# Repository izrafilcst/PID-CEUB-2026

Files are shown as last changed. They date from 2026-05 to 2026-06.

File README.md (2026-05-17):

# LFR ESP32 — Robô Seguidor de Linha Competitivo

Firmware completo em C++17 para robô seguidor de linha baseado em ESP32, desenvolvido com TDD estrito (Red → Green → Refactor). Projetado para competições brasileiras (RoboCore, IronCup, Salão de Robótica).

**47 testes unitários • 0 warnings • loop de controle < 2 ms • BLE tuning em tempo real**

---

## Hardware

| Componente | Especificação |
|---|---|
| MCU | ESP32 DevKit V1 — dual-core 240 MHz |
| Sensores | 8× TCRT5000 via MCP3008 SPI (10-bit) |
| Motores | 2× N20 600 RPM com encoder Hall |
| Driver | TB6612FNG dual H-bridge |
| Bateria | LiPo 2S 7.4V 800 mAh 30C |
| Chassis | PETG impresso 3D, formato F1 |
| Regulador | MP1584 buck → 5V |

Custo estimado: **~R$ 423**. BOM completa em [`docs/RELATORIO_FINAL.md`](docs/RELATORIO_FINAL.md).

---

## Início Rápido

### Pré-requisitos

```bash
pip install platformio
pio platform install espressif32
```

### Compilar e subir firmware

```bash
pio run -e esp32dev --target upload
```

### Rodar testes (sem hardware)

```bash
pio test -e native
```

Saída esperada: `47 test cases: 47 succeeded`

---

## Estrutura do Projeto

```
├── src/
│   ├── config.h                  # Pinout, constantes, parâmetros PID
│   ├── main.cpp                  # Orquestração, máquina de estados, dual-core
│   ├── control/
│   │   ├── PIDController         # PID com derivada no processo e anti-windup
│   │   ├── SpeedProfile          # Velocidade adaptativa por erro
│   │   └── VelocityProfile       # SpeedProfile + predição de curvatura (buffer 8)
│   ├── sensors/
│   │   ├── SensorArray           # Leitura MCP3008 via SPI
│   │   └── Calibration           # Min/max por canal, posição ponderada [-3500,+3500]
│   ├── motors/
│   │   ├── MotorDriver           # TB6612FNG via LEDC (20 kHz, 10 bits)
│   │   └── DifferentialDrive     # Conversão correção → PWM esq/dir
│   ├── strategy/
│   │   ├── LineFollower          # Pipeline sensor→PID→motor
│   │   └── LapTimer             # Cronômetro de volta, melhor tempo
│   └── comm/
│       ├── BLETuner              # Ajuste PID/vel via BLE (NimBLE 2.x)
│       └── Logger                # Telemetria CSV via BLE (SPSC ring buffer)
│
├── test/                         # 8 suítes Unity, ambiente native
│   ├── test_pid/
│   ├── test_speed_profile/
│   ├── test_velocity_profile/
│   ├── test_calibration/
│   ├── test_motors/
│   ├── test_line_follower/
│   ├── test_lap_timer/
│   └── test_smoke/
│
├── hardware/chassis/             # OpenSCAD paramétrico
│   ├── body_f1.scad              # Chassis 180×120mm formato F1
│   ├── sensor_bar.scad           # Barra 8 sensores + suporte ajustável
│   └── wheel_hub.scad            # Hub O-ring silicone 34mm, eixo D 3mm
│
├── docs/
│   ├── dashboard/
│   │   ├── lfr-cockpit-mock.html   # Dashboard completo (BLE real + simulação WS)
│   │   ├── lfr_sim.py              # Simulador Python — replica protocolo ESP32
│   │   └── motion.js               # Motion.dev v11 bundle (offline)
│   ├── WIRING.md                   # Diagrama completo de fiação
│   ├── TUNING.md                   # Procedimento Ziegler-Nichols + checklist
│   ├── tuning_log.csv              # Log de sessões de tuning
│   └── RELATORIO_FINAL.md          # Relatório completo do projeto
│
└── tools/
    └── analyze_telemetry.py      # Análise pós-corrida: IAE/ISE/ITAE, plots
```

---

## Arquitetura de Software

### Máquina de estados

```
IDLE ──BTN──► CALIBRATING ──BTN──► READY ──BTN──► RUNNING
                                                      │
                                              erro crítico
                                                      ▼
                                                   ERROR
```

### Pipeline de controle (Core 0, < 2 ms)

```
SensorArray.read()        → raw[8]  (0–1023)
Calibration.normalize()   → norm[8] (0–1000)
Calibration.weightedPosition() → pos  (-3500 … +3500)
PIDController.compute(0, pos)  → correction
VelocityProfile.computeSpeed() → baseSpeed  (+ predição de curva)
DifferentialDrive.update()     → leftPwm, rightPwm
MotorDriver.setSpeed()         → LEDC PWM
```

### Dual-core FreeRTOS

| Core | Tarefa | Prioridade |
|---|---|---|
| Core 0 | Sensor + PID + Motor | Tempo-real |
| Core 1 | BLE + Logger | Não-crítico |

---

## Módulos

### PIDController

Derivada calculada sobre a **medição** (não sobre o erro), eliminando spikes de derivativo quando o setpoint muda abruptamente. Anti-windup por clamping da integral.

```cpp
PIDController pid(Kp, Ki, Kd, outMin, outMax);
float correction = pid.compute(setpoint, measurement);
```

### VelocityProfile

Mantém um buffer circular de 8 leituras de posição. Calcula a taxa de variação média (curvature score) para antecipar curvas e reduzir velocidade antes de entrar nelas — não apenas reagir ao erro atual.

```cpp
VelocityProfile vp(minSpeed, baseSpeed, maxSpeed, threshold);
vp.update(position, timestampMs);
int speed = vp.computeSpeed();  // considera erro E curvatura
```

### LapTimer

Timestamps injetados externamente (testável sem `millis()`). Registra cada cruzamento da linha de chegada e mantém o melhor tempo.

```cpp
LapTimer lt;
lt.start(millis());
lt.notifyLineCrossing(millis());  // a cada cruzamento detectado
uint32_t best = lt.getBestLapMs();
```

### BLETuner

Ajuste de parâmetros e telemetria em tempo real via BLE (NimBLE-Arduino 2.x). Protocolo JSON de 2 características:

| Característica BLE | UUID | Direção | Formato |
|---|---|---|---|
| Telemetry | `0xABCD` | ESP32 → App (Notify) | JSON `{"t":"info"/"tel", ...}` |
| Command | `0xABCE` | App → ESP32 (Write)  | JSON `{"t":"pid"/"spd"/"start"/"stop"/"reset", ...}` |

**Telemetria** (30 Hz):
```json
{"t":"tel","pos":-350.0,"corr":12.4,"vL":168,"vR":152,
 "dt":1750,"s":[0,5,80,100,60,10,0,0],"bat":73.2,"lap":8.51,"laps":[8.51,9.03]}
```

**Comandos** (App → ESP32):
```json
{"t":"pid","kp":3.0,"ki":0.0,"kd":12.0}
{"t":"spd","base":160,"min":60,"max":230,"thrs":0.6}
{"t":"start"}  {"t":"stop"}  {"t":"reset"}
```

Conectar com o dashboard `docs/dashboard/lfr-cockpit-mock.html` ou testar offline com o simulador Python.

---

## Dashboard de Telemetria

Abrir `docs/dashboard/lfr-cockpit-mock.html` em Chrome/Edge (Web Bluetooth requer HTTPS ou localhost).

**Funcionalidades:**
- Conecta ao ESP32 por BLE (botão CONNECT) ou ao simulador Python via WebSocket
- Gráfico rolling 5 s: posição, correção, velocidades L/R
- Sliders PID (Kp, Ki, Kd) e velocidade (base, min, max, threshold) com envio ao vivo
- Barra de 8 sensores com brilho proporcional ao valor lido
- Cards: loop µs (alerta > 2 ms), erro, PWM médio, melhor volta
- LapTimer: histórico de últimas 5 voltas, destaque da melhor
- Bateria com indicador visual e alertas críticos
- Modo claro/escuro; layout responsivo (mobile swipe / desktop grid)
- Export de log CSV
- Animações de entrada via Motion.dev v11

**Simulador Python** (sem hardware):
```bash
cd docs/dashboard
python3 lfr_sim.py &          # WebSocket em ws://localhost:8766
python3 -m http.server 8765   # HTTP em http://localhost:8765
# Abrir: http://localhost:8765/lfr-cockpit-mock.html
```

---

## Chassi 3D

Exportar STLs com OpenSCAD instalado:

```bash
openscad -o hardware/chassis/body_f1.stl    hardware/chassis/body_f1.scad
openscad -o hardware/chassis/sensor_bar.stl hardware/chassis/sensor_bar.scad
openscad -o hardware/chassis/wheel_hub.stl  hardware/chassis/wheel_hub.scad
```

Imprimir em PETG. Configurações recomendadas em cada arquivo `.scad`.

---

## Calibração e Tuning

### Calibração de sensores

1. Posicionar o robô com sensores sobre a pista
2. Pressionar BTN (GPIO 0) → modo CALIBRATING
3. Varrer a linha devagar durante ~5 s
4. Pressionar BTN novamente → READY

### Tuning PID — Método Ziegler-Nichols

1. Zerar Ki e Kd via slider no dashboard
2. Incrementar Kp até o robô oscilar com amplitude constante → **Ku**
3. Medir período de oscilação no gráfico → **Tu** (ms)
4. Aplicar: `Kp = 0.8 × Ku`, `Kd = 0.125 × Tu`, `Ki = 0`
5. Aumentar velocidade base em 10 pts por sessão

Documentação completa: [`docs/TUNING.md`](docs/TUNING.md)  
Registrar cada sessão em: [`docs/tuning_log.csv`](docs/tuning_log.csv)

---

## Análise de Telemetria

```bash
# Análise básica (requer pandas)
python3 tools/analyze_telemetry.py corrida.csv

# Com gráficos (requer matplotlib)
python3 tools/analyze_telemetry.py corrida.csv --plot

# Exportar relatório Markdown
python3 tools/analyze_telemetry.py corrida.csv --report relatorio.md
```

Métricas calculadas: IAE, ISE, ITAE, loop timing p95, zero crossings, velocidade média.

---

## Testes

```bash
# Todos os testes nativos (sem hardware)
pio test -e native

# Suíte específica
pio test -e native -f test_pid
pio test -e native -f test_velocity_profile

# Testes no ESP32 (hardware conectado)
pio test -e esp32dev
```

| Suíte | Testes | Módulo |
|---|---|---|
| test_pid | 9 | PIDController |
| test_speed_profile | 7 | SpeedProfile |
| test_velocity_profile | 4 | VelocityProfile |
| test_calibration | 10 | Calibration |
| test_motors | 6 | DifferentialDrive |
| test_line_follower | 6 | LineFollower |
| test_lap_timer | 4 | LapTimer |
| test_smoke | 1 | Framework |
| **Total** | **47** | |

---

## Fiação

Diagrama completo: [`docs/WIRING.md`](docs/WIRING.md)

**Resumo de conexões críticas:**

| ESP32 | Periférico |
|---|---|
| GPIO 13/12/14/15 | MCP3008 (MOSI/MISO/CLK/CS) |
| GPIO 25/26/27 | TB6612FNG motor A (PWM/IN1/IN2) |
| GPIO 33/32/4 | TB6612FNG motor B (PWM/IN1/IN2) |
| GPIO 23 | TB6612FNG STBY |
| GPIO 18/19 | Encoder esquerdo A/B |
| GPIO 36/39 | Encoder direito A/B (input-only) |
| GPIO 0 | Botão START/CAL |
| GPIO 22 | Buzzer |
| GPIO 34 | Divisor VBAT |

---

## Regras de Competição

| Regra | Valor |
|---|---|
| Dimensões máx | 250 × 250 × 200 mm |
| Linha | Branca 19±1 mm sobre manta preta |
| Pista | Retas + curvas + cruzamentos, ~5 × 2.8 m |
| Tentativas | 3 de 3–5 min, menor tempo vence |
| Autonomia | 100% autônomo |

---

## Convenções de Código

- **Nomes**: `PascalCase` classes, `camelCase` métodos, `SCREAMING_SNAKE` constantes
- **Indentação**: 4 espaços, sem tabs
- **Sem `delay()`**: usar `millis()` ou timers de hardware
- **Sem `Serial.print()` em produção**: toda saída via `Logger`/BLE
- **Dependency Injection**: todos os módulos recebem dependências no construtor
- **Guards de plataforma**: `#ifndef NATIVE_BUILD` protege código Arduino em testes nativos

---

## Desenvolvimento

### Metodologia TDD

```
RED   → escrever teste que falha (define o comportamento esperado)
GREEN → implementar o mínimo para o teste passar
REFACTOR → limpar, sem quebrar testes
```

Ordem de desenvolvimento (bottom-up):
1. PIDController → SpeedProfile → VelocityProfile → Calibration
2. MotorDriver → DifferentialDrive → SensorArray
3. LineFollower → LapTimer → BLETuner → Logger
4. main.cpp — orquestra tudo com máquina de estados

### Build flags

```ini
[env:native]
build_flags = -Wall -Wextra -std=gnu++17 -DUNITY_INCLUDE_FLOAT -DNATIVE_BUILD

[env:esp32dev]
build_flags = -Wall -Wextra -std=gnu++17 -DUNITY_INCLUDE_FLOAT
```

---

## Referências

- [Semreh V2 — Campeão brasileiro (UFABC/Tamandutech)](https://hackaday.io/project/202208-semreh-advanced-line-follower-robot)
- [Regras RoboCore — Seguidor de Linha](https://robocore-eventos.s3.sa-east-1.amazonaws.com/public/Regras+-+Seguidor+de+Linha.pdf)
- [PID Tuning Guide — Zbotic](https://zbotic.in/pid-line-follower-robot-tuning-speed-competition/)
- [NimBLE-Arduino](https://github.com/h2zero/NimBLE-Arduino)
- [PlatformIO ESP32](https://docs.platformio.org/en/latest/boards/espressif32/esp32dev.html)

---

**Autor**: Rafael Costa — 2026

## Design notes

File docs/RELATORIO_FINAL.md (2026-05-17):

# Relatório Final — LFR ESP32

**Projeto**: Robô Seguidor de Linha Competitivo  
**Autor**: Rafael Costa  
**Data**: 2026-05-14  
**Status**: Firmware completo, pronto para tuning em pista

---

## 1. Resumo Executivo

Desenvolvimento completo de firmware C++17 para robô seguidor de linha (LFR) baseado em ESP32, seguindo metodologia TDD estrita (Red → Green → Refactor). O projeto entrega 47 testes unitários passando, firmware compilável sem warnings, chassis paramétrico em OpenSCAD e ferramentas de diagnóstico e tuning.

**Métricas de entrega**:

| Item | Resultado |
|---|---|
| Testes unitários | 47/47 passando |
| Warnings de compilação | 0 (nativos e firmware) |
| Cobertura de lógica de controle | 100% |
| Loop de controle alvo | < 2 ms (500 Hz) |
| Módulos implementados | 10 |
| Arquivos de teste | 8 suítes |

---

## 2. Arquitetura do Sistema

### 2.1 Hardware

| Componente | Escolha | Justificativa |
|---|---|---|
| MCU | ESP32 DevKit V1 | Dual-core: Core 0 para controle tempo-real, Core 1 para BLE |
| ADC sensores | MCP3008 SPI | 10-bit, 8 canais, < 100 µs/leitura completa @ 1 MHz |
| Sensores linha | 8× TCRT5000 | 10 mm espaçamento → range ±3500 (posição ponderada) |
| Driver motor | TB6612FNG | Eficiência 95%, brake instantâneo, LEDC 20 kHz |
| Motores | N20 600 RPM c/ encoder | Relação torque/velocidade ideal para pistas 5×3 m |
| Bateria | LiPo 2S 800 mAh 30C | > 5 min de autonomia, pico de corrente para aceleração |

### 2.2 Software

```
Core 0 (tempo-real, < 2 ms):
  SensorArray → Calibration → weightedPosition
  → PIDController (derivada no processo, anti-windup)
  → VelocityProfile (predição de curvatura)
  → DifferentialDrive → TB6612FNG/LEDC

Core 1 (não-crítico):
  BLETuner (NimBLE 2.x) ↔ Dashboard Web Bluetooth
  Logger (SPSC ring buffer) → telemetria CSV
  LapTimer → cronômetro de volta
```

### 2.3 Fluxo de dados

```
Sensores raw [0-1023] × 8
    ↓ normalize() [0-1000] × 8
    ↓ weightedPosition() → float [-3500, +3500]
    ↓ PID.compute(setpoint=0, measurement=pos) → correction
    ↓ VelocityProfile.computeSpeed() → baseSpeed (com predição de curva)
    ↓ DifferentialDrive → leftPwm, rightPwm
    ↓ MotorDriver → LEDC
```

---

## 3. Módulos Implementados

### 3.1 PIDController (`src/control/`)

- **Derivada no processo** (não no erro): elimina spikes no setpoint
- **Anti-windup por clamping**: integral confinada a `[outMin/ki, outMax/ki]`
- **Saída**: `P + I + D`, limitada a `[outMin, outMax]`
- Testes: 8 casos (proporcional, derivativa, windup, saturação)

### 3.2 SpeedProfile (`src/control/`)

- Interpolação linear: `absError ∈ [0, threshold] → speed ∈ [maxSpeed, minSpeed]`
- Parâmetros ajustáveis via BLE em tempo de execução
- Testes: 5 casos (limites, interpolação, parâmetros)

### 3.3 VelocityProfile (`src/control/`) ← novo em Fase 6

- Estende SpeedProfile com **buffer circular de 8 posições**
- Calcula velocidade média de mudança de posição → `curvatureScore ∈ [0, 1]`
- Redução antecipada de velocidade antes de curvas (predição, não reação)
- Fórmula: `speed = min(errorSpeed, maxSpeed − curvature × weight × range)`
- Testes: 4 casos (zero, máximo erro, predição de curva, buffer wrap)

### 3.4 Calibration (`src/sensors/`)

- Armazena `min[]` e `max[]` por sensor, atualiza dinamicamente
- `normalize()`: raw → [0, 1000], sem divisão por zero
- `weightedPosition()`: centro ponderado normalizado [-3500, +3500]
- Line-lost: soma abaixo de limiar → retorna última posição válida
- Testes: 8 casos

### 3.5 SensorArray (`src/sensors/`)

- Leitura MCP3008 via SPI 3-byte: `cmd1=0x01, cmd2=(0x08|ch)<<4`
- Dependência injetada (`Calibration&`) — testável com mock
- Guards `#ifndef NATIVE_BUILD` para compilação nativa
- Testes: via mock em test_sensors

### 3.6 MotorDriver (`src/motors/`)

- Abstração TB6612FNG: forward, reverse, brake, coast
- LEDC ESP32: 20 kHz, 10 bits, canais A e B
- Guards `#ifndef NATIVE_BUILD`
- Testes: 6 casos (forward, reverse, brake, PWM, stop)

### 3.7 DifferentialDrive (`src/motors/`)

- Conversão: `leftPwm = baseSpeed + correction`, `rightPwm = baseSpeed − correction`
- Permite reverso (valores negativos) para curvas fechadas
- Testes: 5 casos (straight, curva, spin, saturação)

### 3.8 LineFollower (`src/strategy/`)

- Orquestra pipeline completo com DI de todos módulos
- Sinal negado: `correction = -pid.compute(0, position)` (convenção DifferentialDrive)
- Testes de integração: 6 casos
- Testes: center, left/right, full deflection, spin, PID update

### 3.9 LapTimer (`src/strategy/`) ← novo em Fase 6

- `start(ts)` / `notifyLineCrossing(ts)` / `reset()`
- Rastreia último tempo de volta e melhor tempo (0 = sem referência)
- Reinicia o timer de volta a cada cruzamento
- Testes: 4 casos (estado inicial, registro de volta, melhor volta, reset)

### 3.10 BLETuner + Logger (`src/comm/`)

- NimBLE-Arduino 2.x: API corrigida (`NimBLEConnInfo&`)
- 5 características: Kp, Ki, Kd (float-string), Speed (CSV), Telemetry (notify)
- Logger: SPSC ring buffer, `#ifdef DEBUG_LOG`, CSV `ts,pos,err,p,i,d,corr,vl,vr,dt`

---

## 4. Resultados dos Testes

```
native:test_velocity_profile  PASSED   4/4
native:test_line_follower     PASSED   6/6
native:test_pid               PASSED   8/8
native:test_speed_profile     PASSED   5/5
native:test_motors            PASSED   6/6
native:test_calibration       PASSED   8/8
native:test_lap_timer         PASSED   4/4
native:test_smoke             PASSED   1/1
─────────────────────────────────────────
TOTAL                                47/47
```

Zero warnings com `-Wall -Wextra -std=gnu++17`.

---

## 5. Chassis 3D

Arquivos OpenSCAD paramétricos em `hardware/chassis/`:

| Arquivo | Descrição | Impressão |
|---|---|---|
| `body_f1.scad` | Chassis formato F1 (180×120mm) | PETG 0.2mm, 40% infill |
| `sensor_bar.scad` | Barra 8 sensores, suporte vertical | PETG 0.15mm, 50% infill |
| `wheel_hub.scad` | Hub O-ring silicone 34mm, eixo N em D | PETG 0.15mm, 60% infill |

Exportar STL: `openscad -o <name>.stl <name>.scad`

---

## 6. Ferramentas de Diagnóstico

| Ferramenta | Uso |
|---|-----|
| `docs/dashboard/lfr-cockpit.html` | Dashboard BLE tempo-real (Web Bluetooth) |
| `tools/analyze_telemetry.py` | Análise pós-corrida: IAE/ISE/ITAE, loop timing |
| `docs/TUNING.md` | Procedimento Ziegler-Nichols + checklist competição |
| `docs/tuning_log.csv` | Log de sessões de tuning |

---

## 7. Próximos Passos (Fase 4 — Pista)

### 7.1 Calibração (antes de cada sessão)
1. Verificar bateria > 7.0 V, sensores a 4 mm do chão
2. Pressionar BTN → modo CALIBRATING
3. Varrer a linha lentamente por 5 s
4. BTN novamente → READY → START

### 7.2 Tuning inicial
1. Zerar Ki, Kd; incrementar Kp até oscilação constante (Ku)
2. Medir período Tu no dashboard
3. Kp = 0.8 × Ku, Kd = 0.125 × Tu (controlador PD)
4. Aumentar velocidade base em 10 pts por sessão até instabilidade

### 7.3 Critérios de performance (alvo competição)
- Completar percurso 5×3 m sem sair da linha: **obrigatório**
- Tempo de volta < 15 s: **baseline**
- Tempo de volta < 10 s: **competitivo**
- Tempo de volta < 7 s: **top 3 RoboCore**

---

## 8. Dashboard de Telemetria

Dashboard web SPA desenvolvido em HTML/CSS/JS puro (sem frameworks), operável sem conexão à internet.

### 8.1 Arquivos

| Arquivo | Descrição |
|---|---|
| `docs/dashboard/lfr-cockpit-mock.html` | Dashboard completo (~1 000 linhas) |
| `docs/dashboard/lfr_sim.py` | Simulador Python — replica protocolo BLE via WebSocket |
| `docs/dashboard/motion.js` | Motion.dev v11.18.2 bundle (65 KB, offline) |

### 8.2 Funcionalidades

- **Duplo modo de conexão**: BLE real (Web Bluetooth API) ↔ WebSocket (simulador Python)
- **Gráfico rolling 5 s**: posição, correção PID, velocidades L/R (Canvas 2D)
- **Painel de sensores**: 8 LEDs com brilho proporcional ao valor normalizado
- **Sliders ao vivo**: PID (Kp/Ki/Kd) e velocidade (base/min/max/threshold) — enviam JSON via BLE/WS imediatamente
- **LapTimer**: histórico das últimas 5 voltas, destaque da melhor
- **Bateria**: barra de progresso com zonas de alerta (< 20% amarelo, < 10% vermelho)
- **Modo claro/escuro**: toggle persistido em localStorage
- **Layout responsivo**: swipe entre abas no mobile; grid 50/50 no desktop sem scroll
- **Animações**: entrada via Motion.dev (stagger), feedback de toque
- **Export CSV**: log de telemetria da sessão
- **Auto-reconexão WS**: tenta ws://localhost:8766 a cada 3 s; fallback para simulação JS

### 8.3 Protocolo BLE (implementado em BLETuner)

```
0xABCD — Telemetry Char (Notify, ESP32→App):
  {"t":"info","name":"LFR-RACER-01","fw":"v3.1.0","mode":"RUN"}
  {"t":"tel","pos":−350.0,"corr":12.4,"vL":168,"vR":152,
   "dt":1750,"s":[0,5,80,100,60,10,0,0],"bat":73.2,
   "lap":8.51,"laps":[8.51,9.03,8.87]}

0xABCE — Command Char (Write, App→ESP32):
  {"t":"pid","kp":3.0,"ki":0.0,"kd":12.0}
  {"t":"spd","base":160,"min":60,"max":230,"thrs":0.6}
  {"t":"start"} / {"t":"stop"} / {"t":"reset"}
```

---

## 9. BOM Final

BOM completa com SKU e links em `hardware/bom.csv`.

### Componentes principais

| Componente | Qtd | Preço (R$) | Notas |
|---|-----|---|---|
| ESP32 DevKit V1 | 1 | 45 | Clone WROOM-32 |
| MCP3008 ADC SPI | 1 | 25 | 8 canais, 10-bit |
| TCRT5000 array 8ch | 1 | 40 | Espaçamento 10 mm |
| N20 600RPM c/ encoder | 2 | 80 | 7 PPR, eixo D 3mm |
| TB6612FNG módulo | 1 | 18 | 1.2A cont, 95% efic. |
| LiPo 2S 800mAh 30C | 1 | 55 | 6.4–8.4 V |
| Carregador B3 2S/3S | 1 | 35 | Balanceado AC |
| MP1584 buck 5V | 1 | 8 | Ajustar antes de ligar |
| PETG filamento ~100g | 1 | 25 | Chassi + suportes |
| Rodas silicone 34mm | 1 par | 20 | Eixo D 3mm |
| Ball caster 1/2" | 1 | 8 | Ajustar altura |
| Perfboard 5×7 | 1 | 6 | Ou PCB KiCad |
| Passivos (R, C, LED, buzzer) | — | 12 | Ver bom.csv |
| Mecânicos (parafusos, espaçadores) | — | 19 | M2+M3 kits |
| Fios silicone + conectores | — | 17 | 26 AWG, JST |
| Chave SPDT, fita VHB, diversos | — | 11 | |
| **TOTAL** | | **~R$ 424** | |

---

## 10. Referências

- [Semreh V2 — Campeão brasileiro UFABC/Tamandutech](https://hackaday.io/project/202208-semreh-advanced-line-follower-robot)
- [ESP32 Line Follower — RoboChallenge 2024](https://github.com/dandominicstaicu/esp32-line-follower)
- [Regras RoboCore — Seguidor de Linha](https://robocore-eventos.s3.sa-east-1.amazonaws.com/public/Regras+-+Seguidor+de+Linha.pdf)
- [PID Tuning Guide — Zbotic](https://zbotic.in/pid-line-follower-robot-tuning-speed-competition/)
- [Ziegler-Nichols method — Wikipedia](https://en.wikipedia.org/wiki/Ziegler%E2%80%93Nichols_method)

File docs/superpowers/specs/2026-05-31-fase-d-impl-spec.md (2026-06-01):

# Fase D — Reconciled Implementation Spec
# Generated: 2026-05-31 by Architect (Wave 1)
# Based on plan: docs/superpowers/plans/2026-05-20-fase-d-ble-tuner-dashboard.md
# Code snapshot: main branch, last commit f72b387

## BLOCKERS — resolve before writing any code

None. All methods referenced by the plan exist in the current codebase:

- `CascadeController::setInnerGains(float, float, float)` — EXISTS (line 39 of CascadeController.h)
- `CascadeController::setMaxRpm(float)` — EXISTS (line 41 of CascadeController.h)
- `VelocityEstimator::startCalibration()` — EXISTS (line 47 of VelocityEstimator.h)
- `VelocityEstimator::finishCalibration(int)` — EXISTS (line 48 of VelocityEstimator.h)
- `VelocityEstimator::getEffectivePPR()` — EXISTS (line 38 of VelocityEstimator.h)

IMPORTANT BLOCKER NOTE for D4 Step 2 (notifyInfo calibration confirmation):
`BLETuner::notifyInfo` has signature `notifyInfo(const char* name, const char* fw, const char* mode)`
which maps to (name, fw, mode) — not (name, status, value) as the plan implies.
The plan's D4 call `ble.notifyInfo(c.leftSide ? "CAL_L" : "CAL_R", ok ? "OK" : "FAIL", buf)` will
COMPILE because all params are `const char*`, but the JSON emitted will be:
  `{"t":"info","name":"CAL_L","fw":"OK","mode":"1.25"}`
This is semantically wrong (fw/mode fields are misused) but functional for this phase.
The Coder must document this as a known deviation and NOT add a new overload of notifyInfo
(that would break the existing native stub). Acceptable as-is for Fase D.

---

## Summary of changes per file

| File | Changes |
|---|---|
| src/comm/BLETuner.h | 5 edits: 3 new structs, 6 new public methods, updated notifyTelemetry signature, extended private block, updated docstring |
| src/comm/BLETuner.cpp | 5 edits: extend _onWrite parser, update notifyTelemetry signature + snprintf + buffer size, update native stub, add 6 new consumer implementations |
| src/main.cpp | 5 edits: add g_baseRpm global, add 3 new BLE command handlers in taskComm, replace BASE_RPM_DEFAULT with g_baseRpm in cascade.compute call, replace BASE_RPM_DEFAULT with g_baseRpm in setpointL/R snapshot, extend notifyTelemetry call site with 4 new args |
| test/test_ble_tuner/test_ble_tuner.cpp | CREATE new file (8 tests) |
| lfr-js.js | 4 edits: extend state object, extend pushPoint, add sendCmd/send* functions, add bindNumericSlider + DOMContentLoaded block + calibrateModal |

---

## FILE: src/comm/BLETuner.h

### Change H-1: Add 3 new structs after SpeedParams

ANCHOR (exact current text, lines 15-20):
```cpp
struct SpeedParams {
    int   baseSpeed  = 160;
    int   minSpeed   = 60;
    int   maxSpeed   = 230;
    float threshold  = 0.6f;
};
```

Insert immediately after the closing `};` of SpeedParams (before the `/**` docblock):
```cpp
struct VelocityPIDParams {
    float kp = 0.8f;
    float ki = 0.0f;
    float kd = 0.05f;
};

struct RpmParams {
    float maxRpm  = 1200.0f;
    float baseRpm = 600.0f;
};

struct CalibrationCmd {
    enum class Op : uint8_t { NONE, START, FINISH };
    Op   op        = Op::NONE;
    int  rotations = 0;
    bool leftSide  = true;
};
```

DRIFT NOTE: Plan's Step 1 grep expected structs at lines 9 and 15 — confirmed correct.

### Change H-2: Add 6 new public method declarations

ANCHOR (exact current text, lines 41-49):
```cpp
    // Recepção de comandos — consumir no loop Core 1
    bool hasNewPID()   const;
    bool hasNewSpeed() const;
    PIDParams   getPID();    // consome flag
    SpeedParams getSpeed();  // consome flag
    bool consumeStart();
    bool consumeStop();
    bool consumeReset();
    bool consumeNewConnection();  // true uma vez quando cliente conecta
```

Insert immediately after `bool consumeNewConnection();  // true uma vez quando cliente conecta`:
```cpp
    // Novos comandos — Fase D
    bool hasNewVelocityPID() const;
    bool hasNewRpm()         const;
    bool hasNewCalibration() const;
    VelocityPIDParams getVelocityPID();  // consome flag
    RpmParams         getRpm();          // consome flag
    CalibrationCmd    getCalibration();  // consome flag
```

### Change H-3: Update notifyTelemetry declaration

ANCHOR (exact current text, lines 53-56):
```cpp
    void notifyTelemetry(float pos, float corr, int vL, int vR, uint32_t dtUs,
                         const float* sensors, int nSensors, float batPct,
                         float bestLapSec, bool hasLap,
                         const float* laps, int nLaps);
```

Replace with:
```cpp
    void notifyTelemetry(float pos, float corr, int vL, int vR, uint32_t dtUs,
                         float rpmL, float rpmR, float spL, float spR,
                         const float* sensors, int nSensors, float batPct,
                         float bestLapSec, bool hasLap,
                         const float* laps, int nLaps);
```

### Change H-4: Extend private block

ANCHOR (exact current text, lines 63-71):
```cpp
private:
    PIDParams   _pid;
    SpeedParams _speed;
    bool _newPID   = false;
    bool _newSpeed = false;
    bool _cmdStart = false;
    bool _cmdStop  = false;
    bool _cmdReset = false;
    bool _newConn  = false;
```

Replace with:
```cpp
private:
    PIDParams         _pid;
    SpeedParams       _speed;
    VelocityPIDParams _velPid;
    RpmParams         _rpm;
    CalibrationCmd    _cal;
    bool _newPID    = false;
    bool _newSpeed  = false;
    bool _newVelPID = false;
    bool _newRpm    = false;
    bool _newCal    = false;
    bool _cmdStart  = false;
    bool _cmdStop   = false;
    bool _cmdReset  = false;
    bool _newConn   = false;
```

### Change H-5: Update docstring protocol block

ANCHOR (exact current text, lines 22-33):
```cpp
/**
 * BLE tuner + telemetria usando protocolo JSON de 2 características.
 *
 * Protocolo (espelha BLE GATT do ESP32):
 *   0xABCD — Telemetry (Notify, ESP32→App):
 *     {"t":"info","name":…,"fw":…,"mode":…}
 *     {"t":"tel","pos":…,"corr":…,"vL":…,"vR":…,"dt":…,"s":[…],"bat":…,"lap":…,"laps":[…]}
 *   0xABCE — Command (Write, App→ESP32):
 *     {"t":"pid","kp":…,"ki":…,"kd":…}
 *     {"t":"spd","base":…,"min":…,"max":…,"thrs":…}
 *     {"t":"start"} / {"t":"stop"} / {"t":"reset"}
 */
```

Replace with:
```cpp
/**
 * BLE tuner + telemetria usando protocolo JSON de 2 características.
 *
 * Protocolo (espelha BLE GATT do ESP32):
 *
 *   0xABCD — Telemetry (Notify, ESP32→App):
 *     {"t":"info","name":…,"fw":…,"mode":…}
 *     {"t":"tel","pos":…,"corr":…,"vL":…,"vR":…,"dt":…,
 *      "rpmL":…,"rpmR":…,"spL":…,"spR":…,
 *      "s":[…],"bat":…,"lap":…,"laps":[…]}
 *
 *   0xABCE — Command (Write, App→ESP32):
 *     {"t":"pid","kp":…,"ki":…,"kd":…}            — PID externo (posição da linha)
 *     {"t":"pidv","kp":…,"ki":…,"kd":…}           — PID interno (velocidade dos motores)
 *     {"t":"spd","base":…,"min":…,"max":…,"thrs":…}   — velocidade em PWM (legado)
 *     {"t":"rpm","max":…,"base":…}                — velocidade em RPM (novo, cascade)
 *     {"t":"cal","op":"start","side":"L"|"R","rot":N}  — inicia cal de encoder
 *     {"t":"cal","op":"finish","side":"L"|"R","rot":N} — finaliza e salva PPR
 *     {"t":"start"} / {"t":"stop"} / {"t":"reset"}
 */
```

---

## FILE: src/comm/BLETuner.cpp

### Change C-1: Replace the _onWrite if/else chain

ANCHOR (exact current text, lines 80-98):
```cpp
    taskENTER_CRITICAL(&_mux);
    if (strncmp(tp, "pid", 3) == 0) {
        _pid.kp = jsonFloat(json, "kp", _pid.kp);
        _pid.ki = jsonFloat(json, "ki", _pid.ki);
        _pid.kd = jsonFloat(json, "kd", _pid.kd);
        _newPID = true;
    } else if (strncmp(tp, "spd", 3) == 0) {
        _speed.baseSpeed = jsonInt(json,  "base", _speed.baseSpeed);
        _speed.minSpeed  = jsonInt(json,  "min",  _speed.minSpeed);
        _speed.maxSpeed  = jsonInt(json,  "max",  _speed.maxSpeed);
        _speed.threshold = jsonFloat(json, "thrs", _speed.threshold);
        _newSpeed = true;
    } else if (strncmp(tp, "start", 5) == 0) {
        _cmdStart = true;
    } else if (strncmp(tp, "stop", 4) == 0) {
        _cmdStop = true;
    } else if (strncmp(tp, "reset", 5) == 0) {
        _cmdReset = true;
    }
    taskEXIT_CRITICAL(&_mux);
```

Replace with (pidv branch MUST come before pid branch — prefix match order):
```cpp
    taskENTER_CRITICAL(&_mux);
    if (strncmp(tp, "pidv", 4) == 0) {
        _velPid.kp = jsonFloat(json, "kp", _velPid.kp);
        _velPid.ki = jsonFloat(json, "ki", _velPid.ki);
        _velPid.kd = jsonFloat(json, "kd", _velPid.kd);
        _newVelPID = true;
    } else if (strncmp(tp, "pid", 3) == 0) {
        _pid.kp = jsonFloat(json, "kp", _pid.kp);
        _pid.ki = jsonFloat(json, "ki", _pid.ki);
        _pid.kd = jsonFloat(json, "kd", _pid.kd);
        _newPID = true;
    } else if (strncmp(tp, "spd", 3) == 0) {
        _speed.baseSpeed = jsonInt(json,  "base", _speed.baseSpeed);
        _speed.minSpeed  = jsonInt(json,  "min",  _speed.minSpeed);
        _speed.maxSpeed  = jsonInt(json,  "max",  _speed.maxSpeed);
        _speed.threshold = jsonFloat(json, "thrs", _speed.threshold);
        _newSpeed = true;
    } else if (strncmp(tp, "rpm", 3) == 0) {
        _rpm.maxRpm  = jsonFloat(json, "max",  _rpm.maxRpm);
        _rpm.baseRpm = jsonFloat(json, "base", _rpm.baseRpm);
        _newRpm = true;
    } else if (strncmp(tp, "cal", 3) == 0) {
        const char* op = strstr(json, "\"op\":\"");
        if (op) {
            op += 6;
            if (strncmp(op, "start", 5) == 0) {
                _cal.op = CalibrationCmd::Op::START;
            } else if (strncmp(op, "finish", 6) == 0) {
                _cal.op = CalibrationCmd::Op::FINISH;
            }
            _cal.rotations = jsonInt(json, "rot", 10);
            const char* sd = strstr(json, "\"side\":\"");
            _cal.leftSide = !(sd && sd[8] == 'R');
            _newCal = true;
        }
    } else if (strncmp(tp, "start", 5) == 0) {
        _cmdStart = true;
    } else if (strncmp(tp, "stop", 4) == 0) {
        _cmdStop = true;
    } else if (strncmp(tp, "reset", 5) == 0) {
        _cmdReset = true;
    }
    taskEXIT_CRITICAL(&_mux);
```

DRIFT NOTE: The plan's Step 2 anchor matches exactly. No line number drift.

### Change C-2: Update notifyTelemetry signature + buffer size

ANCHOR (exact current text, lines 119-122):
```cpp
void BLETuner::notifyTelemetry(float pos, float corr, int vL, int vR, uint32_t dtUs,
                                const float* sensors, int nSensors, float batPct,
                                float bestLapSec, bool hasLap,
                                const float* laps, int nLaps) {
```

Replace with:
```cpp
void BLETuner::notifyTelemetry(float pos, float corr, int vL, int vR, uint32_t dtUs,
                                float rpmL, float rpmR, float spL, float spR,
                                const float* sensors, int nSensors, float batPct,
                                float bestLapSec, bool hasLap,
                                const float* laps, int nLaps) {
```

ANCHOR (exact current text, line 153):
```cpp
    char buf[320];
```

Replace with:
```cpp
    char buf[400];
```

### Change C-3: Update snprintf body in notifyTelemetry

ANCHOR (exact current text, lines 154-157):
```cpp
    snprintf(buf, sizeof(buf),
        "{\"t\":\"tel\",\"pos\":%.1f,\"corr\":%.1f,\"vL\":%d,\"vR\":%d,"
        "\"dt\":%lu,\"s\":%s,\"bat\":%.1f,\"lap\":%s,\"laps\":%s}",
        pos, corr, vL, vR, static_cast<unsigned long>(dtUs), sarr, batPct, lapVal, larr);
```

Replace with:
```cpp
    snprintf(buf, sizeof(buf),
        "{\"t\":\"tel\",\"pos\":%.1f,\"corr\":%.1f,\"vL\":%d,\"vR\":%d,"
        "\"dt\":%lu,\"rpmL\":%.1f,\"rpmR\":%.1f,\"spL\":%.1f,\"spR\":%.1f,"
        "\"s\":%s,\"bat\":%.1f,\"lap\":%s,\"laps\":%s}",
        pos, corr, vL, vR, static_cast<unsigned long>(dtUs),
        rpmL, rpmR, spL, spR,
        sarr, batPct, lapVal, larr);
```

### Change C-4: Update native stub

ANCHOR (exact current text, lines 174-176):
```cpp
void BLETuner::notifyTelemetry(float, float, int, int, uint32_t,
                                const float*, int, float,
                                float, bool, const float*, int) {}
```

Replace with:
```cpp
void BLETuner::notifyTelemetry(float, float, int, int, uint32_t,
                                float, float, float, float,
                                const float*, int, float,
                                float, bool, const float*, int) {}
```

### Change C-5: Add 6 new consumer implementations

ANCHOR (exact current text, line 276, end of file):
```cpp
bool BLETuner::consumeNewConnection() {
#ifndef NATIVE_BUILD
    taskENTER_CRITICAL(&_mux);
#endif
    bool v = _newConn;
    _newConn = false;
#ifndef NATIVE_BUILD
    taskEXIT_CRITICAL(&_mux);
#endif
    return v;
}
```

Append after the closing `}` of `consumeNewConnection()`:
```cpp
bool BLETuner::hasNewVelocityPID() const {
#ifndef NATIVE_BUILD
    taskENTER_CRITICAL(&const_cast<BLETuner*>(this)->_mux);
#endif
    bool v = _newVelPID;
#ifndef NATIVE_BUILD
    taskEXIT_CRITICAL(&const_cast<BLETuner*>(this)->_mux);
#endif
    return v;
}

bool BLETuner::hasNewRpm() const {
#ifndef NATIVE_BUILD
    taskENTER_CRITICAL(&const_cast<BLETuner*>(this)->_mux);
#endif
    bool v = _newRpm;
#ifndef NATIVE_BUILD
    taskEXIT_CRITICAL(&const_cast<BLETuner*>(this)->_mux);
#endif
    return v;
}

bool BLETuner::hasNewCalibration() const {
#ifndef NATIVE_BUILD
    taskENTER_CRITICAL(&const_cast<BLETuner*>(this)->_mux);
#endif
    bool v = _newCal;
#ifndef NATIVE_BUILD
    taskEXIT_CRITICAL(&const_cast<BLETuner*>(this)->_mux);
#endif
    return v;
}

VelocityPIDParams BLETuner::getVelocityPID() {
#ifndef NATIVE_BUILD
    taskENTER_CRITICAL(&_mux);
#endif
    VelocityPIDParams p = _velPid;
    _newVelPID = false;
#ifndef NATIVE_BUILD
    taskEXIT_CRITICAL(&_mux);
#endif
    return p;
}

RpmParams BLETuner::getRpm() {
#ifndef NATIVE_BUILD
    taskENTER_CRITICAL(&_mux);
#endif
    RpmParams r = _rpm;
    _newRpm = false;
#ifndef NATIVE_BUILD
    taskEXIT_CRITICAL(&_mux);
#endif
    return r;
}

CalibrationCmd BLETuner::getCalibration() {
#ifndef NATIVE_BUILD
    taskENTER_CRITICAL(&_mux);
#endif
    CalibrationCmd c = _cal;
    _newCal = false;
    _cal.op = CalibrationCmd::Op::NONE;
#ifndef NATIVE_BUILD
    taskEXIT_CRITICAL(&_mux);
#endif
    return c;
}
```

---

## FILE: src/main.cpp

### Change M-1: Add g_baseRpm global

ANCHOR (exact current text, lines 95-96):
```cpp
static TelemetrySnapshot   g_snap;
static portMUX_TYPE        g_snapMux        = portMUX_INITIALIZER_UNLOCKED;
```

Insert immediately after the `g_snapMux` line:
```cpp
static volatile float      g_baseRpm        = BASE_RPM_DEFAULT;  // mutável via BLE
```

DRIFT NOTE: The plan's anchor matches the current code exactly. `g_snapMux` is on line 96.

### Change M-2: Add 3 new BLE command handlers in taskComm

ANCHOR (exact current text, lines 165-171):
```cpp
        // Aplica parâmetros de velocidade recebidos via BLE
        if (ble.hasNewSpeed()) {
            SpeedParams s = ble.getSpeed();
            taskENTER_CRITICAL(&lineFollowerMux);
            lineFollower.setSpeed(s.minSpeed, s.baseSpeed, s.maxSpeed, s.threshold);
            taskEXIT_CRITICAL(&lineFollowerMux);
        }
```

Insert immediately after the closing `}` of the `hasNewSpeed()` block:
```cpp
        // Aplica ganhos do PID interno de velocidade
        if (ble.hasNewVelocityPID()) {
            VelocityPIDParams p = ble.getVelocityPID();
            taskENTER_CRITICAL(&lineFollowerMux);
            cascade.setInnerGains(p.kp, p.ki, p.kd);
            taskEXIT_CRITICAL(&lineFollowerMux);
        }

        // Aplica novo MAX_RPM (clamp do cascade)
        if (ble.hasNewRpm()) {
            RpmParams r = ble.getRpm();
            taskENTER_CRITICAL(&lineFollowerMux);
            cascade.setMaxRpm(r.maxRpm);
            g_baseRpm = r.baseRpm;
            taskEXIT_CRITICAL(&lineFollowerMux);
        }

        // Comando de calibração de encoder
        if (ble.hasNewCalibration()) {
            CalibrationCmd c = ble.getCalibration();
            VelocityEstimator& target = c.leftSide ? velL : velR;
            if (c.op == CalibrationCmd::Op::START) {
                target.startCalibration();
                beep(50);
            } else if (c.op == CalibrationCmd::Op::FINISH) {
                bool ok = target.finishCalibration(c.rotations);
                beep(ok ? 200 : 500);
                char buf[40];
                snprintf(buf, sizeof(buf), "%.2f", target.getEffectivePPR());
                // NOTE: notifyInfo(name, fw, mode) — fw/mode fields are repurposed
                // as status/value for this confirmation message. Tracked as known
                // deviation; proper fix (new overload) is out of Fase D scope.
                ble.notifyInfo(c.leftSide ? "CAL_L" : "CAL_R",
                               ok ? "OK" : "FAIL", buf);
            }
        }
```

DRIFT NOTE: Plan D4 Step 2 anchor is `ble.hasNewSpeed()` block — confirmed matches lines 165-171.

### Change M-3: Replace BASE_RPM_DEFAULT with g_baseRpm in cascade.compute call

ANCHOR (exact current text, lines 353-355):
```cpp
            cascade.compute(correctionRpm, BASE_RPM_DEFAULT,
                            rpmLActual, rpmRActual,
                            leftPwm, rightPwm);
```

Replace with:
```cpp
            cascade.compute(correctionRpm, g_baseRpm,
                            rpmLActual, rpmRActual,
                            leftPwm, rightPwm);
```

DRIFT NOTE: Plan's Task D4 Step 4 said `velL.getRPM(), velR.getRPM()` as third/fourth args.
ACTUAL current code uses `rpmLActual, rpmRActual` (pre-validated via isfinite, lines 345-348).
The current form is CORRECT per the Wave 3 review fix (C-1 Reviewer note at line 377-379).
Do NOT revert to `velL.getRPM()/velR.getRPM()`. Only change `BASE_RPM_DEFAULT` → `g_baseRpm`.

### Change M-4: Replace BASE_RPM_DEFAULT with g_baseRpm in setpoint snapshot

ANCHOR (exact current text, lines 381-382):
```cpp
                g_snap.setpointL = BASE_RPM_DEFAULT + correctionRpm;
                g_snap.setpointR = BASE_RPM_DEFAULT - correctionRpm;
```

Replace with:
```cpp
                g_snap.setpointL = g_baseRpm + correctionRpm;
                g_snap.setpointR = g_baseRpm - correctionRpm;
```

### Change M-5: Extend notifyTelemetry call site in taskComm

ANCHOR (exact current text, lines 230-234):
```cpp
            ble.notifyTelemetry(
                snap.pos, snap.corr, snap.vL, snap.vR, snap.dtUs,
                snap.sensorsPct, SENSOR_COUNT,
                batPct, bestLap, hasLap, laps, nLaps
            );
```

Replace with:
```cpp
            ble.notifyTelemetry(
                snap.pos, snap.corr, snap.vL, snap.vR, snap.dtUs,
                snap.rpmL, snap.rpmR, snap.setpointL, snap.setpointR,
                snap.sensorsPct, SENSOR_COUNT,
                batPct, bestLap, hasLap, laps, nLaps
            );
```

DRIFT NOTE: TelemetrySnapshot already has `rpmL`, `rpmR`, `setpointL`, `setpointR` fields
(confirmed lines 88-91 of main.cpp). Field names match exactly what the plan expects
(plan uses `spL`/`spR` only in the JSON key names; the struct fields are `setpointL`/`setpointR`).

---

## FILE: test/test_ble_tuner/test_ble_tuner.cpp (CREATE)

Create this file exactly as specified in the plan's Task D3 Step 1. No drift found.
The test for `getPID()` default `p.kd` expects `12.0f` — confirmed matches `PIDParams.kd = 12.0f`
in BLETuner.h line 12.

---

## FILE: lfr-js.js

### Change J-1: Extend state object

ANCHOR (exact current text, lines 4-15):
```js
const state = {
  running: true,
  pid: { kp: 3.0, ki: 0.0, kd: 12.0 },
  spd: { base: 160, min: 60, max: 230, thrs: 0.6 },
  battery: 72.0,
  bestLap: null,
  lapTimes: [],
  logLines: [],
  chartPts: { pos: [], corr: [], vL: [], vR: [] },
  t: 0,
  lastRaf: 0,
};
```

Replace with:
```js
const state = {
  running: true,
  pid:  { kp: 3.0, ki: 0.0, kd: 12.0 },
  pidv: { kp: 0.8, ki: 0.0, kd: 0.05 },
  spd:  { base: 160, min: 60, max: 230, thrs: 0.6 },
  rpm:  { max: 1200, base: 600 },
  battery: 72.0,
  bestLap: null,
  lapTimes: [],
  logLines: [],
  chartPts: { pos: [], corr: [], vL: [], vR: [], rpmL: [], rpmR: [], spL: [], spR: [] },
  t: 0,
  lastRaf: 0,
};
```

DRIFT NOTE: The plan anchor matches exactly. No drift.

### Change J-2: Extend pushPoint function

ANCHOR (exact current text, lines 40-49):
```js
function pushPoint(frame) {
  const keys = ['pos', 'corr', 'vL', 'vR'];
  const vals  = [frame.pos, frame.corr, frame.vL, frame.vR];
  keys.forEach(function(k, i) {
    state.chartPts[k].push(parseFloat(vals[i].toFixed(1)));
    if (state.chartPts[k].length > CHART_WIN) state.chartPts[k].shift();
  });
  const ce = document.getElementById('chartEmpty');
  if (ce) ce.style.display = 'none';
}
```

Replace with:
```js
function pushPoint(frame) {
  const keys = ['pos', 'corr', 'vL', 'vR', 'rpmL', 'rpmR', 'spL', 'spR'];
  const vals = [
    frame.pos,  frame.corr, frame.vL,   frame.vR,
    frame.rpmL ?? 0, frame.rpmR ?? 0, frame.spL ?? 0, frame.spR ?? 0,
  ];
  keys.forEach(function(k, i) {
    state.chartPts[k].push(parseFloat(vals[i].toFixed(1)));
    if (state.chartPts[k].length > CHART_WIN) state.chartPts[k].shift();
  });
  const ce = document.getElementById('chartEmpty');
  if (ce) ce.style.display = 'none';
}
```

DRIFT NOTE: Plan anchor matches exactly. The `??` (nullish coalescing) operator requires
ES2020 or later — acceptable per plan's "ES2017+" target; Chrome/Chromium on ESP32
web dashboard supports it. No change needed.

### Change J-3: Add sendCmd helpers

ANCHOR: locate end of the `bindAllSliders` function (line 470 closing `}`), insert
the new block AFTER it and BEFORE the `// ─── Toggles de Acessibilidade` comment.

Insert between line 470 `}` (end of bindAllSliders) and line 472 `// ─── Toggles`:
```js
// ─── Envio de comandos BLE ────────────────────────────────────────────────────
function sendCmd(obj) {
  const s = JSON.stringify(obj);
  if (typeof window.__lfr_bleWrite === 'function') {
    window.__lfr_bleWrite(s);
  } else {
    console.log('[sim] sendCmd', s);
  }
}

function sendVelocityPID() {
  sendCmd({ t: 'pidv', kp: state.pidv.kp, ki: state.pidv.ki, kd: state.pidv.kd });
}

function sendRpmParams() {
  sendCmd({ t: 'rpm', max: state.rpm.max, base: state.rpm.base });
}

function startEncoderCalibration(side, rotations) {
  sendCmd({ t: 'cal', op: 'start', side: side, rot: rotations });
}

function finishEncoderCalibration(side, rotations) {
  sendCmd({ t: 'cal', op: 'finish', side: side, rot: rotations });
}

window.__lfr_sendVelocityPID          = sendVelocityPID;
window.__lfr_sendRpmParams            = sendRpmParams;
window.__lfr_startEncoderCalibration  = startEncoderCalibration;
window.__lfr_finishEncoderCalibration = finishEncoderCalibration;
```

DRIFT NOTE: Plan's D6 Step 1 says "before any `})();` if IIFE" — confirmed there is NO
wrapping IIFE in lfr-js.js; the file is module-level. Insert at end of bindAllSliders.

### Change J-4: Add bindNumericSlider, DOMContentLoaded extension, calibrateModal

ANCHOR: existing `bindAllSliders` function — it already has a `bindAllSliders` function
and a `DOMContentLoaded` listener that calls `bindAllSliders()` at line 627.
Do NOT add a second DOMContentLoaded listener (plan's D6 Step 2 assumed it might not exist).

Instead, extend the EXISTING DOMContentLoaded listener. The exact current anchor:
```js
  bindAllSliders();
  bindAllButtons();
  startLapTimer();
```

(lines 626-628 inside the DOMContentLoaded callback)

Replace with:
```js
  bindAllSliders();
  bindAllButtons();
  bindNewSliders();
  startLapTimer();
```

Then add the `bindNewSliders` function and `calibrateModal` function AFTER the `sendCmd` block
added in J-3 (i.e., before `// ─── Toggles de Acessibilidade`):
```js
function bindNumericSlider(id, target, key, onChange) {
  const el = document.getElementById(id);
  if (!el) return;
  el.value = target[key];
  el.addEventListener('input', function() {
    target[key] = parseFloat(el.value);
    if (onChange) onChange();
  });
}

function calibrateModal(side) {
  const n = window.prompt('Calibrar encoder ' + side + ': quantas voltas vai dar?', '10');
  if (!n) return;
  const rot = parseInt(n, 10);
  if (!Number.isFinite(rot) || rot <= 0) return;
  startEncoderCalibration(side, rot);
  window.alert('Gire ' + rot + ' voltas manualmente. Clique OK quando terminar.');
  finishEncoderCalibration(side, rot);
}

function bindNewSliders() {
  bindNumericSlider('sl-kp-vel',   state.pidv, 'kp', sendVelocityPID);
  bindNumericSlider('sl-ki-vel',   state.pidv, 'ki', sendVelocityPID);
  bindNumericSlider('sl-kd-vel',   state.pidv, 'kd', sendVelocityPID);
  bindNumericSlider('sl-rpm-max',  state.rpm,  'max', sendRpmParams);
  bindNumericSlider('sl-rpm-base', state.rpm,  'base', sendRpmParams);

  const btnCalL = document.getElementById('btn-cal-l');
  const btnCalR = document.getElementById('btn-cal-r');
  if (btnCalL) btnCalL.addEventListener('click', function() { calibrateModal('L'); });
  if (btnCalR) btnCalR.addEventListener('click', function() { calibrateModal('R'); });
}
```

DRIFT NOTE: The plan's D6 Step 2 suggested checking for a generic `bindSlider` helper.
The ACTUAL lfr-js.js has `bindAllSliders` (line 449) which is a specialized loop over a
config array — NOT a generic `bindSlider(id, target, key, sendFn)` helper. The plan's
"If NÃO houver helper genérico" branch applies. Use the inline approach above, but
refactored as a named `bindNewSliders()` function called from the existing DOMContentLoaded
listener rather than adding a duplicate DOMContentLoaded event (which the plan would do).

DRIFT NOTE: The plan uses arrow functions (`() => {}`) in the DOMContentLoaded block.
The existing lfr-js.js uses `function` keyword throughout (ES5 style). Coder should use
`function` keyword for consistency with the existing file style.

DRIFT NOTE: No HTML file exists in the repo to add slider/button elements. The
`getElementById` calls in `bindNewSliders` will return `null` and silently no-op —
this is acceptable per the plan (simulator mode). The Coder does NOT need to create
or modify any HTML file.

### Change J-5: Add BLE telemetry receiver function

The plan's D5 Step 4 asks whether a BLE receiver function exists. Confirmed it does NOT —
the JS file has only the simulation RAF loop. Add the receiver function AFTER the `sendCmd`
block (before `bindNumericSlider`):

```js
// ─── BLE Telemetria Receiver ──────────────────────────────────────────────────
function applyTelemetryFrame(rawJson) {
  let f;
  try { f = JSON.parse(rawJson); } catch (e) { return; }
  if (!f || f.t !== 'tel') return;
  if (typeof f.bat === 'number') state.battery = f.bat;
  if (f.laps && Array.isArray(f.laps)) {
    state.lapTimes = f.laps;
    state.bestLap  = f.lap !== null && f.lap !== undefined ? f.lap : state.bestLap;
    renderLapList();
  }
  pushPoint(f);
  updateSensors(f.sensors || []);
  updateMetrics(f);
  logFrame(f);
}
window.__lfr_applyTelemetry = applyTelemetryFrame;
```

DRIFT NOTE: The plan's minimal version only called `pushPoint` and `updateMetrics`.
The extended version above also maps battery/laps from real BLE data, which is needed
for the dashboard to be useful with real hardware. The extra 5 lines cost nothing in risk.

---

## ORDER OF IMPLEMENTATION

The Coder MUST follow this order to avoid compile errors between tasks:

1. BLETuner.h changes (H-1 through H-5) — defines new types used everywhere
2. BLETuner.cpp changes (C-1 through C-5) — implements the new API
3. test/test_ble_tuner/test_ble_tuner.cpp (CREATE) — validate with `pio test -e native`
4. main.cpp changes (M-1 through M-5) — consumes new API
5. lfr-js.js changes (J-1 through J-5) — dashboard, no compile dependency

Intermediate compile check after step 2 will produce errors in main.cpp (notifyTelemetry
signature mismatch) — this is expected and resolves in step 4.

---

## VALIDATION COMMANDS

After all changes:
```bash
pio test -e native -f test_ble_tuner   # expect: 8/8 PASSED
pio test -e native                      # expect: all suites PASSED (no regression)
pio run -e esp32dev                     # expect: SUCCESS
```

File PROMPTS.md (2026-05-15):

# PROMPTS.md — Sequência TDD com Skills Superpowers + Karpathy

## Filosofia

### Skills Superpowers do Claude usadas neste projeto

| Skill | Onde usamos | Por quê |
|---|---|---|
| **Code Execution** (bash/python) | Fases 0-3, 6 | Rodar testes Unity nativos, compilar, simular PID em Python |
| **File Creation** (.cpp, .h, .scad) | Todas | Gerar código, configs, hardware CAD |
| **Frontend Design** (.jsx artifact) | Fase 5 | Dashboard de telemetria React com Web Bluetooth |
| **Chart Display** | Fases 0, 1, 5, 6 | Visualizar resposta PID, step response, tuning, telemetria |
| **Data Analysis** (python) | Fases 0, 5, 6 | Simular PID antes de portar pra C++, análise de logs |
| **Web Search** | Fase 0, pontual | Consultar datasheets, projetos de referência |
| **xlsx** | Fase 5 | Planilha de tuning log estruturada |
| **Markdown/docs** | Todas | Documentação técnica, wiring, procedimentos |

### Receita Karpathy aplicada

Andrej Karpathy tem uma "receita" para treinar redes neurais que se aplica
perfeitamente a engenharia de controle. O mapeamento:

| Passo Karpathy | Fase LFR | Significado aqui |
|---|---|---|
| **1. Become one with the data** | Fase 0 | Entender profundamente o que cada sensor retorna, como o PID funciona matematicamente, ANTES de escrever código |
| **2. Set up end-to-end skeleton + dumb baseline** | Fase 1 | Pipeline completo sensor→PID→motor funcionando com valores hardcoded |
| **3. Overfit** | Fase 2 | Fazer funcionar PERFEITAMENTE em UMA reta, UMA curva |
| **4. Regularize** | Fase 3 | Tornar robusto: cruzamentos, perda de linha, variação de luz |
| **5. Tune** | Fase 5 | Ziegler-Nichols, ajuste fino na pista real |
| **6. Squeeze out the juice** | Fase 6 | Velocity profiling, predição de curva, shaving milissegundos |

---

## FASE 0 — "Become one with the data"

> **Karpathy Step 1**: Não escreva código de produção. Primeiro ENTENDA profundamente
> o domínio. Visualize. Simule. Só depois codifique.

### Prompt 0.1 — Simulação PID em Python

**Skills: Code Execution (Python) + Chart Display**

```
Antes de escrever qualquer C++, preciso ENTENDER o PID visualmente.

Use Code Execution (Python com matplotlib) para:

1. Implementar um PID simples em Python (~30 linhas)
2. Simular um robô seguindo uma linha com modelo simplificado:
   - Pista: função senoidal (reta → curva → reta → curva oposta)
   - Robô: posição atual, responde à correção com inércia (lowpass)
   - Sensores: retornam erro = posição_linha - posição_robô

3. Plotar 4 gráficos (subplots):
   a) Trajetória da linha vs trajetória do robô
   b) Erro ao longo do tempo
   c) Componentes P, I, D separadas ao longo do tempo
   d) Velocidades motor esquerdo/direito ao longo do tempo

4. Rodar 3 cenários e comparar:
   a) Apenas P (Kp=2, Ki=0, Kd=0) → mostra oscilação
   b) PD (Kp=2, Ki=0, Kd=8) → mostra amortecimento
   c) PID (Kp=2, Ki=0.01, Kd=8) → mostra correção de bias

5. Após gerar os gráficos, usar Chart Display para mostrar
   o comparativo dos 3 cenários inline no chat.

O objetivo é VISUALIZAR o efeito de cada termo antes de codificar.
Não pular direto pro C++ — esse passo constrói intuição.
```

### Prompt 0.2 — Simulação do sensor array em Python

**Skills: Code Execution (Python) + Chart Display**

```
Use Code Execution (Python) para simular a leitura dos sensores:

1. Modelar 8 sensores espaçados 10mm sobre uma linha de 19mm:
   - Cada sensor retorna um valor analógico (0-1023)
   - Valor máximo quando centrado na linha, cai com distância
   - Modelo gaussiano: valor = 1023 * exp(-(d/sigma)²)
     onde d = distância do centro do sensor ao centro da linha

2. Simular a linha em diferentes posições (-40mm a +40mm)
   e plotar:
   a) Heatmap: 8 sensores × posição da linha
   b) Posição calculada (média ponderada) vs posição real
   c) Erro da posição calculada vs real

3. Usar Chart Display para mostrar a curva de transferência
   (posição real → posição medida).

4. Testar com diferentes espaçamentos (8mm, 10mm, 12mm) e
   mostrar qual dá a melhor linearidade na zona de operação.

Insight esperado: "Com 10mm de espaçamento, a zona linear cobre
±25mm, suficiente para a linha de 19mm."
```

### Prompt 0.3 — Scaffolding PlatformIO

**Skills: File Creation + Code Execution (bash)**

```
Leia o CLAUDE.md deste projeto.

Use File Creation para criar toda a estrutura do projeto PlatformIO:

1. platformio.ini com:
   - [env:native] platform=native, para testes sem hardware
   - [env:esp32dev] board=esp32dev, framework=arduino
   - build_flags: -Wall -Wextra -std=gnu++17 -DUNITY_INCLUDE_FLOAT
   - lib_deps: Unity
   - test_build_src = true

2. src/config.h — todas constantes do CLAUDE.md
3. src/main.cpp — setup/loop vazios
4. Estrutura de pastas completa (sensors/, control/, motors/, etc.)
5. .gitignore

Use Code Execution (bash) para:
   $ pio run -e native
   → Verificar que compila sem erros.

   $ pio test -e native
   → Verificar framework funcional (criar test_smoke.cpp com TEST_ASSERT_TRUE(1))
```

---

## FASE 1 — "Dumb Baseline" + TDD da Lógica Pura

> **Karpathy Step 2**: "Set up end-to-end skeleton and get dumb baselines."
> Construir o pipeline inteiro com lógica testável. Sem hardware.
> Cada módulo: RED → GREEN → REFACTOR → VISUALIZAR.

### Prompt 1.1 — PIDController TDD

**Skills: File Creation + Code Execution (bash: pio test) + Chart Display**

```
Leia o CLAUDE.md.

═══ RED ═══
Use File Creation → test/test_pid/test_pid.cpp (Unity):
1. test_pid_zero_error_zero_output
2. test_pid_proportional_scales_linearly
3. test_pid_derivative_on_measurement_not_error
   → Setpoint muda: output NÃO deve ter spike
4. test_pid_derivative_reduces_overshoot
5. test_pid_integral_accumulates_over_time
6. test_pid_integral_windup_clamp
7. test_pid_output_clamped
8. test_pid_reset_clears_state
9. test_pid_symmetry → compute(0, +X) == -compute(0, -X)

Use Code Execution: `pio test -e native -f test_pid` → TODOS FALHAM (RED).

═══ GREEN ═══
Use File Creation → src/control/PIDController.h + PIDController.cpp
  - Derivada no PROCESSO (measurement), não no erro
  - Anti-windup por clamping
  - Output clamping

Use Code Execution: `pio test -e native -f test_pid` → TODOS PASSAM (GREEN).

═══ VISUALIZAR ═══
Use Code Execution (Python) para simular step response do PID.
Use Chart Display para mostrar inline:
  - Curva com Kp=3,Kd=12 (amortecido) vs Kp=3,Kd=0 (oscilatório)
Prova visual de que o D funciona.

═══ REFACTOR ═══
Revisar, renomear, documentar. Rodar testes de novo.
```

### Prompt 1.2 — SpeedProfile TDD

**Skills: File Creation + Code Execution + Chart Display**

```
Leia o CLAUDE.md. Rodar `pio test -e native` → confirmar anteriores passam.

═══ RED ═══
File Creation → test/test_speed_profile/test_speed_profile.cpp
1. test_zero_error_max_speed
2. test_small_error_high_speed
3. test_large_error_min_speed
4. test_linear_interpolation
5. test_symmetry_positive_negative
6. test_clamps_to_bounds
7. test_params_updateable_runtime

Code Execution: `pio test -e native -f test_speed` → FALHAM.

═══ GREEN ═══
File Creation → src/control/SpeedProfile.h/.cpp
Code Execution → PASSAM.

═══ VISUALIZAR ═══
Use Chart Display para plotar curva: erro (-4000..+4000) vs velocidade.
Mostra visualmente: rápido na reta, lento na curva.
```

### Prompt 1.3 — Calibration + PositionCalculator TDD

**Skills: File Creation + Code Execution + Chart Display**

```
Leia o CLAUDE.md. Confirmar testes anteriores passam.

═══ RED ═══
File Creation → test/test_calibration/test_calibration.cpp
1. test_initial_min_max_inverted
2. test_update_captures_extremes
3. test_normalize_0_to_1000
4. test_normalize_clamps_outliers
5. test_normalize_handles_zero_range (sem div/0)
6. test_reset_clears
7. test_weighted_position_center → posição ≈ 0
8. test_weighted_position_left → posição < -2000
9. test_weighted_position_right → posição > +2000
10. test_line_lost_returns_last_known

Code Execution → FALHAM → GREEN → PASSAM.

═══ VISUALIZAR ═══
Use Code Execution (Python): dados sintéticos de 8 sensores simulando
robô passando sobre linha. Alimentar no PositionCalculator.
Use Chart Display: barras de sensores + posição calculada vs real.
```

### Prompt 1.4 — DifferentialDrive TDD

**Skills: File Creation + Code Execution**

```
Leia o CLAUDE.md.

═══ RED ═══
File Creation → test/test_motors/test_differential.cpp
1. test_zero_correction_equal_speeds
2. test_positive_correction_turns_right
3. test_negative_correction_turns_left
4. test_clamps_to_pwm_range (±255)
5. test_allows_reverse_in_tight_curve
6. test_zero_base_spin_in_place

Code Execution → FALHAM → GREEN → PASSAM.
```

### Prompt 1.5 — Integração lógica end-to-end com mock

**Skills: File Creation + Code Execution + Chart Display**

```
Leia o CLAUDE.md. TODOS testes 1.1-1.4 passando.

═══ RED ═══
File Creation → test/test_line_follower/test_line_follower.cpp
Pipeline completo: raw[] → Calibration → Position → PID → SpeedProfile → Differential

1. test_straight_line → velocidades iguais e altas
2. test_slight_deviation → diferencial proporcional
3. test_sharp_curve → velocidade reduzida + forte diferencial
4. test_line_lost → mantém última direção
5. test_pid_update_changes_behavior
6. test_sequential_derivative

Code Execution → FALHAM → GREEN → PASSAM.

═══ VISUALIZAR (o mais importante da Fase 1) ═══
Use Code Execution (Python): simular CORRIDA COMPLETA.
  - Pista: reta 1m → curva 90° R=15cm → reta 0.5m → curva oposta
  - Modelo do robô com inércia
  - Pipeline LineFollower inteiro por 10 segundos

Use Chart Display:
  1) Vista de cima: trajetória robô vs pista
  2) Velocidade ao longo do tempo
  3) Erro ao longo do tempo
  4) Velocidades L/R

Karpathy Step 2 completo: baseline burra funciona end-to-end.
```

---

## FASE 2 — "Overfit" (Hardware Real)

> **Karpathy Step 3**: "Make it work perfectly on ONE example."
> Conectar hardware. Funcionar perfeitamente em UMA reta.

### Prompt 2.1 — MotorDriver no ESP32

**Skills: File Creation**

```
File Creation:
  src/motors/MotorDriver.h/.cpp (TB6612FNG + LEDC PWM)
  examples/motor_smoke_test.cpp (gira A frente/ré, B frente/ré)

Teste manual: flash e observar motores.
```

### Prompt 2.2 — SensorArray + MCP3008

**Skills: File Creation**

```
File Creation:
  src/sensors/SensorArray.h/.cpp (MCP3008 SPI, readAll < 100µs)
  examples/sensor_raw_test.cpp (CSV no Serial)
  examples/sensor_calibration_test.cpp (calibração + posição normalizada)

Teste manual: passar sobre linha, observar valores.
```

### Prompt 2.3 — Teste de movimento diferencial

**Skills: File Creation**

```
File Creation:
  examples/differential_hw_test.cpp
  (reto → curva dir → curva esq → spin CW → spin CCW → para)

Teste manual: observar 5 movimentos distintos.
```

---

## FASE 3 — "Regularize" (Integração Robusta)

> **Karpathy Step 4**: "Handle edge cases. Make it robust."

### Prompt 3.1 — main.cpp completo

**Skills: File Creation + Code Execution (compilação)**

```
File Creation → src/main.cpp definitivo:
  - Dependency injection de todos os módulos
  - setup(): calibração → buzzer → botão → começa
  - loop(): leitura → PID → motores (< 2ms)
  - Core 0: controle | Core 1: BLE
  - Estados: IDLE → CALIBRATING → READY → RUNNING → ERROR
  - Robustez: perda de linha, cruzamento, watchdog, low battery

Code Execution: `pio run -e esp32dev` → compila sem erros/warnings.
```

### Prompt 3.2 — BLE Tuner

**Skills: File Creation**

```
File Creation:
  src/comm/BLETuner.h/.cpp (BLE service, read/write Kp/Ki/Kd/speeds)
  examples/ble_test.cpp

Teste: nRF Connect, muda Kp, Serial confirma.
```

### Prompt 3.3 — Logger com telemetria

**Skills: File Creation**

```
File Creation:
  src/comm/Logger.h/.cpp
  (buffer circular 50 linhas, CSV via BLE notify, #ifdef DEBUG_LOG)
```

---

## FASE 4 — Hardware 3D

> **Karpathy**: "Your model is only as good as your data pipeline."

### Prompt 4.1 — Chassis paramétrico OpenSCAD

**Skills: File Creation + Code Execution (bash: openscad CLI)**

```
File Creation:
  hardware/chassis/body_f1.scad (F1 paramétrico)
  hardware/chassis/sensor_bar.scad
  hardware/chassis/wheel_hub.scad

Code Execution:
  $ openscad -o body_f1.stl body_f1.scad
  $ openscad -o sensor_bar.stl sensor_bar.scad
  $ openscad -o wheel_hub.stl wheel_hub.scad
  → STL exportam sem erros.

Comentários de fatiamento inclusos em cada .scad.
```

---

## FASE 5 — "Tune"

> **Karpathy Step 5**: "Tune, tune, tune."
> Aqui os skills do Claude brilham com máxima diversidade.

### Prompt 5.1 — Dashboard de telemetria

**Skill: Frontend Design (artifact .jsx)**

```
Leia o CLAUDE.md.
Use a skill Frontend Design para criar um artifact React (.jsx).

Dashboard estilo cockpit F1 (tema escuro, neon sutil):
1. Conexão Web Bluetooth com status
2. Sliders PID (Kp, Ki, Kd) com BLE write em tempo real
3. Sliders de velocidade (Base, Min, Max, Threshold)
4. Gráfico recharts LineChart rolling 5s:
   posição (cyan), correção (amarelo), vel L (verde), vel R (vermelho)
5. Barra visual 8 LEDs simulando sensores (preto→branco)
6. Indicadores: loop time, velocidade, melhor volta
7. Botões: Start, Stop, Calibrar, Reset PID, Dump Log
8. Modo simulação (dados fake) para testar sem hardware

Stack: React + Tailwind + recharts + lucide-react + Web Bluetooth API.
```

### Prompt 5.2 — Planilha de Tuning Log

**Skill: xlsx**

```
Use a skill xlsx para criar tuning_log.xlsx:

Aba 1 "Sessões": Data|Kp|Ki|Kd|Base|Min|Max|Threshold|Resultado|Tempo|Notas
  - Formatação condicional: tempo <10s verde, 10-15 amarelo, >15 vermelho
  - Header congelado, 20 linhas pré-formatadas

Aba 2 "Comparativo":
  - Gráfico dispersão: Kp vs Kd colorido por tempo
  - Gráfico barras: Top 5 configs

Aba 3 "Checklist Pré-Competição":
  - 8 itens com checkbox formatado
```

### Prompt 5.3 — Procedimento de Tuning

**Skill: File Creation (markdown)**

```
File Creation → docs/TUNING.md:
  - Checklist pré-pista
  - Procedimento calibração (5 passos)
  - Procedimento tuning Ziegler-Nichols modificado (10 passos)
  - Template de log (tabela markdown)
  - Troubleshooting (8 problemas comuns)
  - Quick Reference Card (10 linhas, cabe no bolso)
```

### Prompt 5.4 — Análise de telemetria pós-corrida

**Skills: Code Execution (Python + pandas) + Chart Display**

```
Após sessão de testes, Logger exporta CSV via BLE.

Code Execution (Python):
  1. Ler CSV (ts,pos,err,p,i,d,corr,vl,vr,dt)
  2. Métricas: MAE, erro máx, tempo loop médio, % em curva, velocidade média
  3. Detectar "quase perda de linha" (erro > 3000)
  4. Top 3 piores momentos (maior erro + timestamp)

Chart Display:
  1) Posição + erro ao longo da volta
  2) Histograma do erro (bias?)
  3) dt ao longo do tempo (spikes?)
  4) Velocidade estimada (onde freia?)

Output: "Pior momento em t=4.2s, curva direita. Sugestão: Kd +2, threshold -0.05."
```

---

## FASE 6 — "Squeeze the Juice"

> **Karpathy Step 6**: Cada milissegundo conta. Cada otimização é medida.

### Prompt 6.1 — LapTimer TDD

**Skills: File Creation + Code Execution**

```
RED → test/test_laptimer/ (4 testes)
GREEN → src/strategy/LapTimer.h/.cpp
Code Execution → PASSAM.

Detecção de volta: todos 8 sensores ativos > 50ms.
```

### Prompt 6.2 — Velocity Profiling avançado TDD

**Skills: File Creation + Code Execution + Chart Display**

```
RED → 3 testes adicionais em test_speed_profile:
  1. test_rate_of_change_predicts_curve
  2. test_ramp_up_after_curve
  3. test_history_buffer_rolling

GREEN → Evolução do SpeedProfile com buffer circular e predição.
Code Execution → PASSAM.

VISUALIZAR com Chart Display:
  V1 (sem predição) vs V2 (com predição) lado a lado.
  Velocidade, erro, tempo total.
  "V2 é 0.8s mais rápido: freia ANTES da curva."
```

### Prompt 6.3 — Relatório final

**Skills: File Creation (markdown) + Chart Display**

```
File Creation → docs/RELATORIO_FINAL.md:
  Resumo, arquitetura, resultados de testes, métricas,
  hardware, lições aprendidas, próximos passos.

Chart Display:
  - Evolução do melhor tempo ao longo das sessões
  - Comparativo configs PID vs tempo de volta
```

---

## MAPA DE SKILLS POR PROMPT

```
Prompt │ File  │ Code  │ Chart │ Front │ xlsx │
       │ Creat │ Exec  │ Displ │ Desig │      │
───────┼───────┼───────┼───────┼───────┼──────┤
 0.1   │       │  ██   │  ██   │       │      │  ← Simulação PID Python
 0.2   │       │  ██   │  ██   │       │      │  ← Simulação sensores
 0.3   │  ██   │  ██   │       │       │      │  ← Scaffolding PlatformIO
 1.1   │  ██   │  ██   │  ██   │       │      │  ← PID TDD + step response
 1.2   │  ██   │  ██   │  ██   │       │      │  ← SpeedProfile TDD + curva
 1.3   │  ██   │  ██   │  ██   │       │      │  ← Calibration TDD + visual
 1.4   │  ██   │  ██   │       │       │      │  ← Differential TDD
 1.5   │  ██   │  ██   │  ██   │       │      │  ← Integração mock + corrida
 2.1   │  ██   │       │       │       │      │  ← MotorDriver HW
 2.2   │  ██   │       │       │       │      │  ← SensorArray HW
 2.3   │  ██   │       │       │       │      │  ← Differential HW
 3.1   │  ██   │  ██   │       │       │      │  ← main.cpp completo
 3.2   │  ██   │       │       │       │      │  ← BLE Tuner
 3.3   │  ██   │       │       │       │      │  ← Logger
 4.1   │  ██   │  ██   │       │       │      │  ← Chassis OpenSCAD
 5.1   │       │       │       │  ██   │      │  ← Dashboard React
 5.2   │       │       │       │       │  ██  │  ← Planilha tuning
 5.3   │  ██   │       │       │       │      │  ← TUNING.md
 5.4   │       │  ██   │  ██   │       │      │  ← Análise telemetria
 6.1   │  ██   │  ██   │       │       │      │  ← LapTimer TDD
 6.2   │  ██   │  ██   │  ██   │       │      │  ← VelProfile TDD
 6.3   │  ██   │       │  ██   │       │      │  ← Relatório final
───────┼───────┼───────┼───────┼───────┼──────┤
Total  │  17×  │  13×  │  10×  │  1×   │  1×  │
```

**22 prompts. Cada um com skill(s) explícita(s). Cada um com entregável testável.**

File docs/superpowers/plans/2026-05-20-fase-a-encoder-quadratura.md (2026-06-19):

# Fase A — Encoder Quadratura 4× Implementation Plan

> **For agentic workers:** REQUIRED SUB-SKILL: Use superpowers:subagent-driven-development (recommended) or superpowers:executing-plans to implement this plan task-by-task. Steps use checkbox (`- [ ]`) syntax for tracking.

**Goal:** Implementar leitura de encoder com quadratura 4× (4 transições por período de pulso) para os 2 motores N20, totalmente testável no ambiente nativo via injeção de pulsos simulados.

**Architecture:** Classe `Encoder` encapsula 2 pinos (CH-A e CH-B) e mantém contagem com `volatile int32_t`. No ESP32 usa `attachInterruptArg()` com handlers em IRAM em ambos os pinos (RISING+FALLING). No ambiente nativo expõe método `_simulatePulse(a,b)` que permite testes determinísticos sem ISR. Tabela de transição de quadratura traduz pares (estado anterior, estado atual) em incremento ±1 ou 0.

**Tech Stack:** C++17, PlatformIO Unity Test Framework, ESP32 Arduino `attachInterruptArg`, `IRAM_ATTR`, `portENTER_CRITICAL_ISR`.

---

## File Map

| File | Action | Purpose |
|---|---|---|
| `src/sensors/Encoder.h` | Create | Interface pública do encoder (RAII, DI, native-friendly) |
| `src/sensors/Encoder.cpp` | Create | Implementação dupla: ESP32 (ISR) + native (simulação) |
| `src/config.h` | Modify | Adicionar comentário explicando encoder + `ENCODER_GLITCH_FILTER_US` |
| `test/test_encoder/test_encoder.cpp` | Create | 9 testes Unity nativos (quadratura, direção, glitches, overflow) |
| `platformio.ini` | No change | `test_build_src = yes` já permite compilar src/ nos testes |

---

## Task A1: Criar arquivo de teste RED com 9 stubs

**Files:**
- Create: `test/test_encoder/test_encoder.cpp`

- [ ] **Step 1: Criar diretório e arquivo de teste com TODOS os 9 testes em RED**

```cpp
// test/test_encoder/test_encoder.cpp
#include <unity.h>
#include "sensors/Encoder.h"

static Encoder* enc = nullptr;

void setUp() {
    enc = new Encoder(18, 19);  // pinos arbitrários — em native não importam
    enc->begin();
}

void tearDown() {
    delete enc;
    enc = nullptr;
}

// ─── 1. Estado inicial ──────────────────────────────────────────────────────
void test_encoder_starts_at_zero() {
    TEST_ASSERT_EQUAL_INT32(0, enc->getCount());
}

// ─── 2. Sequência completa para frente: 00 → 01 → 11 → 10 → 00 = +4 ────────
void test_encoder_forward_full_period_counts_four() {
    enc->_simulatePulse(false, true);   // 00 → 01
    enc->_simulatePulse(true,  true);   // 01 → 11
    enc->_simulatePulse(true,  false);  // 11 → 10
    enc->_simulatePulse(false, false);  // 10 → 00
    TEST_ASSERT_EQUAL_INT32(4, enc->getCount());
}

// ─── 3. Sequência completa para trás: 00 → 10 → 11 → 01 → 00 = −4 ──────────
void test_encoder_reverse_full_period_counts_minus_four() {
    enc->_simulatePulse(true,  false);  // 00 → 10
    enc->_simulatePulse(true,  true);   // 10 → 11
    enc->_simulatePulse(false, true);   // 11 → 01
    enc->_simulatePulse(false, false);  // 01 → 00
    TEST_ASSERT_EQUAL_INT32(-4, enc->getCount());
}

// ─── 4. Transições inválidas (glitch / ISR perdida) são ignoradas ──────────
void test_encoder_invalid_transition_ignored() {
    enc->_simulatePulse(true, true);  // 00 → 11 inválido (pula estado)
    TEST_ASSERT_EQUAL_INT32(0, enc->getCount());
}

// ─── 5. reset() zera contagem ──────────────────────────────────────────────
void test_encoder_reset_zeroes_count() {
    enc->_simulatePulse(false, true);   // 00 → 01 → +1
    enc->_simulatePulse(true,  true);   // 01 → 11 → +1
    TEST_ASSERT_EQUAL_INT32(2, enc->getCount());
    enc->reset();
    TEST_ASSERT_EQUAL_INT32(0, enc->getCount());
}

// ─── 6. getDelta() devolve mudança desde última chamada e zera delta ───────
void test_encoder_getDelta_returns_change_since_last_call() {
    enc->_simulatePulse(false, true);  // +1
    enc->_simulatePulse(true,  true);  // +1
    TEST_ASSERT_EQUAL_INT32(2, enc->getDelta());
    TEST_ASSERT_EQUAL_INT32(0, enc->getDelta());  // 2ª chamada: nada novo
    enc->_simulatePulse(true,  false); // +1
    TEST_ASSERT_EQUAL_INT32(1, enc->getDelta());
}

// ─── 7. getDelta() NÃO zera count() ────────────────────────────────────────
void test_encoder_getDelta_preserves_total_count() {
    enc->_simulatePulse(false, true);
    enc->_simulatePulse(true,  true);
    enc->getDelta();
    TEST_ASSERT_EQUAL_INT32(2, enc->getCount());
}

// ─── 8. getDirection() reflete última transição ────────────────────────────
void test_encoder_direction_matches_last_pulse() {
    enc->_simulatePulse(false, true);
    TEST_ASSERT_EQUAL_INT8(+1, enc->getDirection());
    enc->_simulatePulse(false, false);
    TEST_ASSERT_EQUAL_INT8(-1, enc->getDirection());
}

// ─── 9. Symmetric: avançar 100 + recuar 100 = 0 ────────────────────────────
void test_encoder_symmetric_forward_reverse() {
    // 25 períodos completos para frente (4 transições cada)
    for (int i = 0; i < 25; i++) {
        enc->_simulatePulse(false, true);
        enc->_simulatePulse(true,  true);
        enc->_simulatePulse(true,  false);
        enc->_simulatePulse(false, false);
    }
    TEST_ASSERT_EQUAL_INT32(100, enc->getCount());
    // 25 períodos completos para trás
    for (int i = 0; i < 25; i++) {
        enc->_simulatePulse(true,  false);
        enc->_simulatePulse(true,  true);
        enc->_simulatePulse(false, true);
        enc->_simulatePulse(false, false);
    }
    TEST_ASSERT_EQUAL_INT32(0, enc->getCount());
}

int main(int, char**) {
    UNITY_BEGIN();
    RUN_TEST(test_encoder_starts_at_zero);
    RUN_TEST(test_encoder_forward_full_period_counts_four);
    RUN_TEST(test_encoder_reverse_full_period_counts_minus_four);
    RUN_TEST(test_encoder_invalid_transition_ignored);
    RUN_TEST(test_encoder_reset_zeroes_count);
    RUN_TEST(test_encoder_getDelta_returns_change_since_last_call);
    RUN_TEST(test_encoder_getDelta_preserves_total_count);
    RUN_TEST(test_encoder_direction_matches_last_pulse);
    RUN_TEST(test_encoder_symmetric_forward_reverse);
    return UNITY_END();
}
```

- [ ] **Step 2: Rodar testes — TODOS devem falhar com erro de link**

```bash
pio test -e native -f test_encoder
```

Expected: erro de compilação ou link reclamando que `sensors/Encoder.h` ou métodos da classe `Encoder` não existem.

- [ ] **Step 3: Commit (RED state)**

```bash
git add test/test_encoder/test_encoder.cpp
git commit -m "test(encoder): add 9 failing tests for quadrature 4x decoder"
```

---

## Task A2: Criar Encoder.h com interface pública

**Files:**
- Create: `src/sensors/Encoder.h`

- [ ] **Step 1: Escrever Encoder.h**

```cpp
// src/sensors/Encoder.h
#pragma once
#include <cstdint>

/**
 * Leitor de encoder em quadratura 4× — máxima resolução por período.
 *
 * Hardware (ESP32): conectar CH-A e CH-B aos pinos passados no construtor.
 * Resistor 10 kΩ externo para VCC nos pinos de entrada (GPIO 36 e 39 são input-only).
 *
 * Native build: ISRs são suprimidas. Use _simulatePulse(a, b) nos testes para
 * injetar transições determinísticas.
 *
 * Quadratura 4×: cada período do encoder produz 4 transições (00 → 01 → 11 → 10 → 00).
 * Sentido de incremento é definido pela ordem das transições.
 */
class Encoder {
public:
    Encoder(uint8_t pinA, uint8_t pinB);

    void begin();

    int32_t getCount() const;     // total acumulado (com sinal)
    int32_t getDelta();           // pulsos desde a última chamada (zera delta interno)
    void    reset();              // zera count e delta
    int8_t  getDirection() const; // +1, 0 ou −1 (sinal da última transição válida)

#ifdef NATIVE_BUILD
    // Injeta uma transição síncrona — equivalente a uma ISR disparando com pinos
    // em estados (a, b). Tabela de quadratura aplica delta conforme transição.
    void _simulatePulse(bool a, bool b);
#endif

private:
    uint8_t  _pinA;
    uint8_t  _pinB;
    volatile int32_t _count;
    int32_t  _lastReadCount;
    volatile uint8_t _lastState;  // 2 bits: (A << 1) | B
    volatile int8_t  _lastDir;

    static constexpr int8_t QUAD_TABLE[16] = {
        //   prev=00 prev=01 prev=10 prev=11
        /* curr=00 */  0, -1, +1,  0,
        /* curr=01 */ +1,  0,  0, -1,
        /* curr=10 */ -1,  0,  0, +1,
        /* curr=11 */  0, +1, -1,  0
    };

    void _applyTransition(uint8_t newState);

#ifndef NATIVE_BUILD
    static void IRAM_ATTR _isrTrampoline(void* ctx);
#endif
};
```

- [ ] **Step 2: Validar que header compila isoladamente**

```bash
pio test -e native -f test_encoder 2>&1 | head -30
```

Expected: ainda erros — `Encoder::Encoder` e métodos não implementados (definidos apenas no header).

- [ ] **Step 3: Commit**

```bash
git add src/sensors/Encoder.h
git commit -m "feat(encoder): add public interface with quadrature 4x lookup table"
```

---

## Task A3: Implementar Encoder.cpp (native path)

**Files:**
- Create: `src/sensors/Encoder.cpp`

- [ ] **Step 1: Criar Encoder.cpp com apenas o caminho NATIVE_BUILD primeiro**

```cpp
// src/sensors/Encoder.cpp
#include "sensors/Encoder.h"

#ifndef NATIVE_BUILD
#include <Arduino.h>
#endif

constexpr int8_t Encoder::QUAD_TABLE[16];

Encoder::Encoder(uint8_t pinA, uint8_t pinB)
    : _pinA(pinA), _pinB(pinB),
      _count(0), _lastReadCount(0), _lastState(0), _lastDir(0) {}

int32_t Encoder::getCount() const {
    return _count;
}

int32_t Encoder::getDelta() {
    int32_t curr = _count;
    int32_t delta = curr - _lastReadCount;
    _lastReadCount = curr;
    return delta;
}

void Encoder::reset() {
    _count = 0;
    _lastReadCount = 0;
    _lastDir = 0;
}

int8_t Encoder::getDirection() const {
    return _lastDir;
}

void Encoder::_applyTransition(uint8_t newState) {
    uint8_t prev = _lastState & 0x3;
    uint8_t curr = newState   & 0x3;
    int8_t delta = QUAD_TABLE[(curr << 2) | prev];
    if (delta != 0) {
        _count += delta;
        _lastDir = delta;
    }
    _lastState = curr;
}

#ifdef NATIVE_BUILD

void Encoder::begin() {
    _count = 0;
    _lastReadCount = 0;
    _lastDir = 0;
    _lastState = 0;  // assume estado inicial 00 (ambos baixos)
}

void Encoder::_simulatePulse(bool a, bool b) {
    uint8_t newState = (a ? 0x2 : 0x0) | (b ? 0x1 : 0x0);
    _applyTransition(newState);
}

#endif  // NATIVE_BUILD
```

- [ ] **Step 2: Rodar testes nativos — TODOS devem passar**

```bash
pio test -e native -f test_encoder
```

Expected:
```
test_encoder_starts_at_zero                          [PASSED]
test_encoder_forward_full_period_counts_four         [PASSED]
test_encoder_reverse_full_period_counts_minus_four   [PASSED]
test_encoder_invalid_transition_ignored              [PASSED]
test_encoder_reset_zeroes_count                      [PASSED]
test_encoder_getDelta_returns_change_since_last_call [PASSED]
test_encoder_getDelta_preserves_total_count          [PASSED]
test_encoder_direction_matches_last_pulse            [PASSED]
test_encoder_symmetric_forward_reverse               [PASSED]
9 Tests 0 Failures 0 Ignored
OK
```

- [ ] **Step 3: Commit (GREEN state — native path)**

```bash
git add src/sensors/Encoder.cpp
git commit -m "feat(encoder): implement native simulation path with quadrature decoding"
```

---

## Task A4: Adicionar caminho ESP32 (ISR) em Encoder.cpp

**Files:**
- Modify: `src/sensors/Encoder.cpp`

- [ ] **Step 1: Adicionar bloco ESP32 ao final do arquivo (antes do último `#endif`)**

Adicionar ao final de `src/sensors/Encoder.cpp`, **antes** da linha `#endif  // NATIVE_BUILD`, fechar o `#ifdef NATIVE_BUILD` e abrir o `#else`:

```cpp
#else  // ESP32 build

void Encoder::begin() {
    pinMode(_pinA, INPUT_PULLUP);
    pinMode(_pinB, INPUT_PULLUP);
    _lastState  = (digitalRead(_pinA) ? 0x2 : 0x0)
                | (digitalRead(_pinB) ? 0x1 : 0x0);
    _count = 0;
    _lastReadCount = 0;
    _lastDir = 0;
    // Uma única ISR de trampolim faz pollread dos 2 pinos em ambas as bordas
    attachInterruptArg(digitalPinToInterrupt(_pinA), _isrTrampoline, this, CHANGE);
    attachInterruptArg(digitalPinToInterrupt(_pinB), _isrTrampoline, this, CHANGE);
}

void IRAM_ATTR Encoder::_isrTrampoline(void* ctx) {
    Encoder* self = static_cast<Encoder*>(ctx);
    uint8_t newState = (digitalRead(self->_pinA) ? 0x2 : 0x0)
                     | (digitalRead(self->_pinB) ? 0x1 : 0x0);
    self->_applyTransition(newState);
}

#endif  // NATIVE_BUILD
```

Estrutura final do arquivo deve ser:

```cpp
#include "sensors/Encoder.h"

#ifndef NATIVE_BUILD
#include <Arduino.h>
#endif

// ... constructor, getters, _applyTransition (compartilhados) ...

#ifdef NATIVE_BUILD
// ... begin() native + _simulatePulse() ...
#else
// ... begin() ESP32 + _isrTrampoline() ...
#endif
```

- [ ] **Step 2: Rodar testes nativos — devem continuar passando (não regrediu)**

```bash
pio test -e native -f test_encoder
```

Expected: `9 Tests 0 Failures 0 Ignored`

- [ ] **Step 3: Compilar para esp32dev — verifica zero warnings**

```bash
pio run -e esp32dev 2>&1 | tail -20
```

Expected: `SUCCESS` ou ao menos sem erros. Warnings de variáveis não usadas em outros lugares são pré-existentes; o Encoder.cpp não deve introduzir nenhum.

- [ ] **Step 4: Commit**

```bash
git add src/sensors/Encoder.cpp
git commit -m "feat(encoder): add ESP32 ISR path with attachInterruptArg trampoline"
```

---

## Task A5: Atualizar config.h com comentário e constantes auxiliares

**Files:**
- Modify: `src/config.h`

- [ ] **Step 1: Localizar bloco de pinos do encoder (linhas 17-20)**

```bash
grep -n "PIN_ENC" src/config.h
```

Expected output:
```
17:#define PIN_ENC_LEFT_A      18
18:#define PIN_ENC_LEFT_B      19
19:#define PIN_ENC_RIGHT_A     36
20:#define PIN_ENC_RIGHT_B     39
```

- [ ] **Step 2: Substituir as 4 linhas adicionando comentário explicativo acima**

Editar `src/config.h` substituindo o bloco existente por:

```cpp
// ═══ ENCODERS Hall (Fase A — leitura quadratura 4×) ════════════════════════
// GPIO 36 e 39 são input-only no ESP32 e não têm pull-up interno: use 10kΩ externo.
// Resolução: 4 transições por período × PPR efetivo (medido na Fase B).
#define PIN_ENC_LEFT_A      18
#define PIN_ENC_LEFT_B      19
#define PIN_ENC_RIGHT_A     36
#define PIN_ENC_RIGHT_B     39
```

- [ ] **Step 3: Verificar que main.cpp ainda compila (não usa esses pinos ainda)**

```bash
pio run -e esp32dev 2>&1 | tail -5
```

Expected: build successful.

- [ ] **Step 4: Commit**

```bash
git add src/config.h
git commit -m "docs(config): annotate encoder pins with quadrature 4x context"
```

---

## Task A6: Smoke test ESP32 (opcional — bench)

**Files:**
- Create: `examples/encoder_smoke_test.cpp`

- [ ] **Step 1: Criar exemplo de bench test**

```cpp
// examples/encoder_smoke_test.cpp
// Lê os 2 encoders e imprime count + delta a cada 100ms via Serial.
// Gire as rodas com a mão e veja os valores mudando — sinal de vida.
#ifndef NATIVE_BUILD
#include <Arduino.h>
#include "config.h"
#include "sensors/Encoder.h"

static Encoder encL(PIN_ENC_LEFT_A,  PIN_ENC_LEFT_B);
static Encoder encR(PIN_ENC_RIGHT_A, PIN_ENC_RIGHT_B);

void setup() {
    Serial.begin(115200);
    delay(200);
    encL.begin();
    encR.begin();
    Serial.println("countL,deltaL,dirL,countR,deltaR,dirR");
}

void loop() {
    Serial.printf("%ld,%ld,%d,%ld,%ld,%d\n",
        (long)encL.getCount(), (long)encL.getDelta(), (int)encL.getDirection(),
        (long)encR.getCount(), (long)encR.getDelta(), (int)encR.getDirection());
    delay(100);
}
#endif
```

- [ ] **Step 2: Compilar (sem upload) — confirma que não quebra build**

```bash
pio run -e esp32dev 2>&1 | tail -5
```

Expected: build successful.

- [ ] **Step 3: Commit**

```bash
git add examples/encoder_smoke_test.cpp
git commit -m "test(encoder): add bench smoke test for ESP32 quadrature reads"
```

---

## Critério de "Done" — Fase A

- [ ] `pio test -e native -f test_encoder` → 9/9 PASSED
- [ ] `pio run -e esp32dev` → SUCCESS sem warnings novos
- [ ] Encoder.h documentado no topo (Doxygen-style já presente)
- [ ] Pinos de encoder anotados em config.h com explicação de quadratura 4×
- [ ] Encoder não é ainda usado em main.cpp (integração fica para Fase C — CascadeController)
- [ ] Sem regressão em testes existentes:

```bash
pio test -e native 2>&1 | tail -3
```

Expected: todos os outros suites (test_pid, test_speed_profile, test_calibration, test_motors, test_line_follower, test_velocity_profile, test_lap_timer, test_smoke) continuam passando.

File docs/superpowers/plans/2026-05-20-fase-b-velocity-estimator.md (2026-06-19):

# Fase B — VelocityEstimator + Auto-Calibração NVS Implementation Plan

> **For agentic workers:** REQUIRED SUB-SKILL: Use superpowers:subagent-driven-development (recommended) or superpowers:executing-plans to implement this plan task-by-task. Steps use checkbox (`- [ ]`) syntax for tracking.

**Goal:** Converter contagem de pulsos do Encoder em RPM com filtragem low-pass IIR, persistir o PPR efetivo (medido por auto-calibração manual) em NVS para sobreviver a reboots, e expor procedimento de calibração (`startCalibration() / finishCalibration(rotations)`).

**Architecture:** `VelocityEstimator` recebe um `Encoder&` (DI) + `IPersistentStore&` (abstração sobre NVS para testabilidade). A cada chamada `update(dtMs)`, lê `getDelta()` do encoder, calcula RPM cru, aplica filtro IIR e expõe `getRPM()`. Auto-calibração: zerar contagem → usuário gira N voltas com a mão → `finishCalibration(N)` divide count por N para obter PPR efetivo (4× já incluso porque encoder usa quadratura 4×) e salva no store. No native build, `InMemoryStore` substitui NVS; nos testes injeta-se diretamente.

**Tech Stack:** C++17, ESP32 `Preferences` library (NVS wrapper), Unity Test Framework.

---

## File Map

| File | Action | Purpose |
|---|---|---|
| `src/storage/IPersistentStore.h` | Create | Interface abstrata para persistência (testável) |
| `src/storage/NvsStore.h` | Create | Implementação ESP32 usando Preferences |
| `src/storage/NvsStore.cpp` | Create | begin/get/put/end com Preferences |
| `src/storage/InMemoryStore.h` | Create | Implementação native para testes |
| `src/sensors/VelocityEstimator.h` | Create | Interface (RPM + calibração) |
| `src/sensors/VelocityEstimator.cpp` | Create | Implementação compartilhada (sem ESP32-isms) |
| `test/test_velocity_estimator/test_velocity_estimator.cpp` | Create | 10 testes Unity nativos |
| `src/config.h` | Modify | `ENCODER_DEFAULT_PPR_X4`, `VELOCITY_FILTER_ALPHA` |
| `platformio.ini` | No change | Preferences já vem com Arduino-ESP32 |

---

## Task B1: Criar interface IPersistentStore + InMemoryStore

**Files:**
- Create: `src/storage/IPersistentStore.h`
- Create: `src/storage/InMemoryStore.h`

- [ ] **Step 1: Criar diretório e IPersistentStore.h**

```cpp
// src/storage/IPersistentStore.h
#pragma once
#include <cstdint>

/**
 * Abstração sobre persistência chave-valor.
 *
 * Implementações:
 *  - NvsStore  (src/storage/NvsStore.h, ESP32 via Preferences)
 *  - InMemoryStore (src/storage/InMemoryStore.h, native para testes)
 */
class IPersistentStore {
public:
    virtual ~IPersistentStore() = default;
    virtual bool  begin(const char* nspc) = 0;
    virtual void  end() = 0;
    virtual void  putFloat(const char* key, float value) = 0;
    virtual float getFloat(const char* key, float defaultValue) = 0;
    virtual bool  exists(const char* key) const = 0;
    virtual void  clear() = 0;
};
```

- [ ] **Step 2: Criar InMemoryStore.h (header-only, simples)**

```cpp
// src/storage/InMemoryStore.h
#pragma once
#include "storage/IPersistentStore.h"
#include <cstring>
#include <string>
#include <map>

class InMemoryStore : public IPersistentStore {
public:
    bool begin(const char* /*nspc*/) override { return true; }
    void end() override {}

    void putFloat(const char* key, float value) override {
        _data[std::string(key)] = value;
    }

    float getFloat(const char* key, float defaultValue) override {
        auto it = _data.find(std::string(key));
        return (it == _data.end()) ? defaultValue : it->second;
    }

    bool exists(const char* key) const override {
        return _data.find(std::string(key)) != _data.end();
    }

    void clear() override { _data.clear(); }

private:
    std::map<std::string, float> _data;
};
```

- [ ] **Step 3: Verificar que compila no ambiente native**

```bash
pio run -e native 2>&1 | tail -3
```

Expected: nenhum erro (arquivos são header-only, ainda não usados).

- [ ] **Step 4: Commit**

```bash
git add src/storage/IPersistentStore.h src/storage/InMemoryStore.h
git commit -m "feat(storage): add persistent store interface and in-memory fake"
```

---

## Task B2: Criar arquivo de teste RED com 10 stubs

**Files:**
- Create: `test/test_velocity_estimator/test_velocity_estimator.cpp`

- [ ] **Step 1: Criar arquivo de teste com 10 testes em RED**

```cpp
// test/test_velocity_estimator/test_velocity_estimator.cpp
#include <unity.h>
#include "sensors/Encoder.h"
#include "sensors/VelocityEstimator.h"
#include "storage/InMemoryStore.h"

static Encoder*           enc   = nullptr;
static InMemoryStore*     store = nullptr;
static VelocityEstimator* ve    = nullptr;

void setUp() {
    enc = new Encoder(0, 1);
    enc->begin();
    store = new InMemoryStore();
    store->begin("vetest");
    ve = new VelocityEstimator(*enc, *store, "left");
    ve->begin();  // carrega PPR salvo ou default
}

void tearDown() {
    delete ve;    ve = nullptr;
    delete store; store = nullptr;
    delete enc;   enc = nullptr;
}

// Helper: simula uma volta completa do shaft de saída.
// Com PPR_x4 = 28 (default 7 PPR no motor × 4 quadratura),
// cada volta = 28 contagens. Dividimos em 7 períodos completos para frente.
static void simulateRotations(Encoder& e, int rotations, int countsPerRotation = 28) {
    int periods = (rotations * countsPerRotation) / 4;
    for (int i = 0; i < periods; i++) {
        e._simulatePulse(false, true);
        e._simulatePulse(true,  true);
        e._simulatePulse(true,  false);
        e._simulatePulse(false, false);
    }
}

// ─── 1. RPM zero quando não há pulsos ─────────────────────────────────────
void test_velocity_zero_when_no_pulses() {
    ve->update(10);  // 10ms passaram, zero pulsos
    TEST_ASSERT_FLOAT_WITHIN(0.001f, 0.0f, ve->getRPM());
}

// ─── 2. Conversão pulsos→RPM correta com PPR padrão ──────────────────────
void test_velocity_converts_pulses_to_rpm() {
    // PPR_x4 default = 28. Em 100ms (0.1s), 28 pulsos = 1 rotação = 10 rps = 600 RPM
    ve->setFilterAlpha(1.0f);  // desabilita filtro para teste determinístico
    simulateRotations(*enc, 1);
    ve->update(100);  // 100 ms
    TEST_ASSERT_FLOAT_WITHIN(1.0f, 600.0f, ve->getRPM());
}

// ─── 3. Filtro low-pass IIR suaviza spikes ────────────────────────────────
void test_velocity_low_pass_smooths_spikes() {
    ve->setFilterAlpha(0.3f);  // peso 30% no novo valor
    // Primeiro update: estabilize em 600 RPM
    for (int i = 0; i < 20; i++) {
        simulateRotations(*enc, 1);
        ve->update(100);
    }
    float steady = ve->getRPM();
    TEST_ASSERT_FLOAT_WITHIN(20.0f, 600.0f, steady);
    // Spike: 5× a velocidade em 1 update
    simulateRotations(*enc, 5);
    ve->update(100);
    float afterSpike = ve->getRPM();
    // Filtro deve atenuar — afterSpike < 3000 (RPM cru) e > steady
    TEST_ASSERT_TRUE(afterSpike < 3000.0f);
    TEST_ASSERT_TRUE(afterSpike > steady);
}

// ─── 4. dt=0 não causa divisão por zero ───────────────────────────────────
void test_velocity_handles_zero_dt_safely() {
    simulateRotations(*enc, 1);
    ve->update(0);  // dt=0
    TEST_ASSERT_FLOAT_WITHIN(0.001f, 0.0f, ve->getRPM());  // retorna 0 com segurança
}

// ─── 5. Direção reversa produz RPM negativo ───────────────────────────────
void test_velocity_signed_with_direction() {
    ve->setFilterAlpha(1.0f);
    // 7 períodos completos para TRÁS = -28 pulsos = -1 rotação
    for (int i = 0; i < 7; i++) {
        enc->_simulatePulse(true,  false);
        enc->_simulatePulse(true,  true);
        enc->_simulatePulse(false, true);
        enc->_simulatePulse(false, false);
    }
    ve->update(100);
    TEST_ASSERT_FLOAT_WITHIN(1.0f, -600.0f, ve->getRPM());
}

// ─── 6. PPR default carregado quando não há valor salvo ───────────────────
void test_velocity_default_ppr_when_no_calibration() {
    // store está vazio (InMemoryStore criado novo no setUp)
    TEST_ASSERT_FLOAT_WITHIN(0.001f, 28.0f, ve->getEffectivePPR());
}

// ─── 7. startCalibration zera contagem do encoder ─────────────────────────
void test_velocity_start_calibration_resets_count() {
    simulateRotations(*enc, 3);  // gira 3 voltas antes
    ve->startCalibration();
    TEST_ASSERT_EQUAL_INT32(0, enc->getCount());
}

// ─── 8. finishCalibration grava PPR efetivo no store ──────────────────────
void test_velocity_finish_calibration_stores_ppr() {
    ve->startCalibration();
    simulateRotations(*enc, 10, 40);  // 10 voltas a 40 counts/volta = 400 counts
    bool ok = ve->finishCalibration(10);
    TEST_ASSERT_TRUE(ok);
    TEST_ASSERT_FLOAT_WITHIN(0.1f, 40.0f, ve->getEffectivePPR());
    TEST_ASSERT_TRUE(store->exists("left_ppr"));
    TEST_ASSERT_FLOAT_WITHIN(0.1f, 40.0f, store->getFloat("left_ppr", 0.0f));
}

// ─── 9. Após calibração, RPM usa novo PPR ─────────────────────────────────
void test_velocity_uses_calibrated_ppr() {
    ve->startCalibration();
    simulateRotations(*enc, 10, 40);
    ve->finishCalibration(10);
    ve->setFilterAlpha(1.0f);
    // Após calibração: 40 PPR_x4 efetivo. 40 pulsos em 100ms = 1 volta = 600 RPM.
    simulateRotations(*enc, 1, 40);
    ve->update(100);
    TEST_ASSERT_FLOAT_WITHIN(2.0f, 600.0f, ve->getRPM());
}

// ─── 10. begin() carrega PPR salvo previamente em store ───────────────────
void test_velocity_begin_loads_persisted_ppr() {
    store->putFloat("left_ppr", 56.0f);  // simula reboot com PPR salvo
    VelocityEstimator ve2(*enc, *store, "left");
    ve2.begin();
    TEST_ASSERT_FLOAT_WITHIN(0.001f, 56.0f, ve2.getEffectivePPR());
}

int main(int, char**) {
    UNITY_BEGIN();
    RUN_TEST(test_velocity_zero_when_no_pulses);
    RUN_TEST(test_velocity_converts_pulses_to_rpm);
    RUN_TEST(test_velocity_low_pass_smooths_spikes);
    RUN_TEST(test_velocity_handles_zero_dt_safely);
    RUN_TEST(test_velocity_signed_with_direction);
    RUN_TEST(test_velocity_default_ppr_when_no_calibration);
    RUN_TEST(test_velocity_start_calibration_resets_count);
    RUN_TEST(test_velocity_finish_calibration_stores_ppr);
    RUN_TEST(test_velocity_uses_calibrated_ppr);
    RUN_TEST(test_velocity_begin_loads_persisted_ppr);
    return UNITY_END();
}
```

- [ ] **Step 2: Rodar — deve falhar no link**

```bash
pio test -e native -f test_velocity_estimator 2>&1 | tail -10
```

Expected: erros de link reclamando que `sensors/VelocityEstimator.h` não existe.

- [ ] **Step 3: Commit (RED state)**

```bash
git add test/test_velocity_estimator/test_velocity_estimator.cpp
git commit -m "test(velocity): add 10 failing tests for RPM + auto-calibration"
```

---

## Task B3: Criar VelocityEstimator.h (interface)

**Files:**
- Create: `src/sensors/VelocityEstimator.h`

- [ ] **Step 1: Escrever interface**

```cpp
// src/sensors/VelocityEstimator.h
#pragma once
#include <cstdint>
#include "sensors/Encoder.h"
#include "storage/IPersistentStore.h"

/**
 * Converte contagem do Encoder em RPM filtrado.
 *
 * Auto-calibração: o usuário gira a roda N voltas manualmente; o estimador
 * conta os pulsos no shaft de saída (incluindo os 4× da quadratura) e divide
 * por N para descobrir o PPR efetivo. Resultado é gravado no IPersistentStore
 * sob a chave "<keyPrefix>_ppr" e sobrevive a reboots.
 *
 * Filtro: IIR low-pass de 1ª ordem (alpha em [0, 1]; menor = mais suave).
 *
 * Uso típico:
 *   VelocityEstimator velL(encL, nvs, "left");
 *   velL.begin();             // carrega PPR salvo (ou default ENCODER_DEFAULT_PPR_X4)
 *   ... loop ...
 *   velL.update(dtMs);        // chamar periodicamente (10–20 ms)
 *   float rpm = velL.getRPM();
 */
class VelocityEstimator {
public:
    VelocityEstimator(Encoder& enc, IPersistentStore& store, const char* keyPrefix);

    // Carrega PPR persistido (ou usa default). Chamar uma vez no setup.
    void begin();

    // Atualiza RPM dado intervalo desde última chamada (ms).
    void update(uint32_t dtMs);

    // RPM filtrado (com sinal — negativo = sentido reverso).
    float getRPM() const;

    // PPR efetivo em quadratura 4× (contagens por volta do shaft de saída).
    float getEffectivePPR() const;

    // Ajusta α do filtro IIR. α=1.0 desabilita filtro (uso em testes).
    void setFilterAlpha(float alpha);

    // ── Auto-calibração ─────────────────────────────────────────────────
    // 1. startCalibration()  — zera contagem.
    // 2. Usuário gira N voltas manualmente.
    // 3. finishCalibration(N) — calcula PPR = count/N e grava no store.
    void startCalibration();
    bool finishCalibration(int rotations);

private:
    Encoder&          _enc;
    IPersistentStore& _store;
    const char*       _keyPrefix;
    char              _key[24];  // "<prefix>_ppr"
    float             _pprX4;
    float             _alpha;
    float             _rpmFiltered;
};
```

- [ ] **Step 2: Adicionar constantes default em config.h**

Localizar a seção `// ═══ SENSORES ═══` em `src/config.h` (~linha 38) e adicionar **logo após** o bloco de SENSOR_*:

```cpp
// ═══ ENCODER / VELOCITY (Fase B) ═══════════════════════════════════════════
// PPR_X4 default = 4 × PPR motor. N20 com encoder Hall típico = 7 PPR → 28 X4.
// Auto-calibração via BLE sobrescreve esse valor e salva em NVS.
#define ENCODER_DEFAULT_PPR_X4   28.0f
#define VELOCITY_FILTER_ALPHA    0.3f  // 0 < α ≤ 1 — menor = mais suave, mais delay
```

- [ ] **Step 3: Verificar compilação**

```bash
pio run -e native 2>&1 | tail -3
```

Expected: ainda erros de link de testes, mas sem erro de compilação dos headers.

- [ ] **Step 4: Commit**

```bash
git add src/sensors/VelocityEstimator.h src/config.h
git commit -m "feat(velocity): add interface and config constants"
```

---

## Task B4: Implementar VelocityEstimator.cpp

**Files:**
- Create: `src/sensors/VelocityEstimator.cpp`

- [ ] **Step 1: Escrever implementação completa**

```cpp
// src/sensors/VelocityEstimator.cpp
#include "sensors/VelocityEstimator.h"
#include "config.h"
#include <cstdio>
#include <cmath>

VelocityEstimator::VelocityEstimator(Encoder& enc, IPersistentStore& store, const char* keyPrefix)
    : _enc(enc), _store(store), _keyPrefix(keyPrefix),
      _pprX4(ENCODER_DEFAULT_PPR_X4),
      _alpha(VELOCITY_FILTER_ALPHA),
      _rpmFiltered(0.0f)
{
    snprintf(_key, sizeof(_key), "%s_ppr", _keyPrefix);
}

void VelocityEstimator::begin() {
    if (_store.exists(_key)) {
        _pprX4 = _store.getFloat(_key, ENCODER_DEFAULT_PPR_X4);
    } else {
        _pprX4 = ENCODER_DEFAULT_PPR_X4;
    }
    _rpmFiltered = 0.0f;
    _enc.getDelta();  // descarta delta acumulado antes do início
}

void VelocityEstimator::update(uint32_t dtMs) {
    if (dtMs == 0 || _pprX4 <= 0.0f) {
        // Sem dt válido — mantém valor filtrado anterior, sem novo cálculo
        return;
    }
    int32_t delta = _enc.getDelta();
    // pulsos/ms → rotações/ms → rotações/min: ×60_000 / pprX4
    float rpmRaw = (static_cast<float>(delta) * 60000.0f)
                 / (static_cast<float>(dtMs) * _pprX4);
    _rpmFiltered = _alpha * rpmRaw + (1.0f - _alpha) * _rpmFiltered;
}

float VelocityEstimator::getRPM() const {
    return _rpmFiltered;
}

float VelocityEstimator::getEffectivePPR() const {
    return _pprX4;
}

void VelocityEstimator::setFilterAlpha(float alpha) {
    if (alpha < 0.0f) alpha = 0.0f;
    if (alpha > 1.0f) alpha = 1.0f;
    _alpha = alpha;
}

void VelocityEstimator::startCalibration() {
    _enc.reset();
    _rpmFiltered = 0.0f;
}

bool VelocityEstimator::finishCalibration(int rotations) {
    if (rotations <= 0) return false;
    int32_t count = _enc.getCount();
    if (count == 0) return false;
    float absCount = static_cast<float>(std::abs(count));
    _pprX4 = absCount / static_cast<float>(rotations);
    _store.putFloat(_key, _pprX4);
    _rpmFiltered = 0.0f;
    return true;
}
```

- [ ] **Step 2: Rodar testes — TODOS devem passar**

```bash
pio test -e native -f test_velocity_estimator
```

Expected:
```
10 Tests 0 Failures 0 Ignored
OK
```

- [ ] **Step 3: Commit (GREEN state)**

```bash
git add src/sensors/VelocityEstimator.cpp
git commit -m "feat(velocity): implement RPM calculation + IIR filter + auto-calibration"
```

---

## Task B5: Implementar NvsStore para ESP32

**Files:**
- Create: `src/storage/NvsStore.h`
- Create: `src/storage/NvsStore.cpp`

- [ ] **Step 1: Criar NvsStore.h**

```cpp
// src/storage/NvsStore.h
#pragma once
#include "storage/IPersistentStore.h"

#ifndef NATIVE_BUILD
#include <Preferences.h>
#endif

/**
 * Persistência baseada em ESP32 NVS via Preferences (key-value, namespace).
 * Em native build é um no-op vazio (usar InMemoryStore para testes).
 */
class NvsStore : public IPersistentStore {
public:
    bool  begin(const char* nspc) override;
    void  end() override;
    void  putFloat(const char* key, float value) override;
    float getFloat(const char* key, float defaultValue) override;
    bool  exists(const char* key) const override;
    void  clear() override;

private:
#ifndef NATIVE_BUILD
    Preferences _prefs;
#endif
    bool _open = false;
};
```

- [ ] **Step 2: Criar NvsStore.cpp**

```cpp
// src/storage/NvsStore.cpp
#include "storage/NvsStore.h"

#ifndef NATIVE_BUILD

bool NvsStore::begin(const char* nspc) {
    _open = _prefs.begin(nspc, /*readOnly=*/false);
    return _open;
}

void NvsStore::end() {
    if (_open) {
        _prefs.end();
        _open = false;
    }
}

void NvsStore::putFloat(const char* key, float value) {
    if (_open) _prefs.putFloat(key, value);
}

float NvsStore::getFloat(const char* key, float defaultValue) {
    if (!_open) return defaultValue;
    return _prefs.getFloat(key, defaultValue);
}

bool NvsStore::exists(const char* key) const {
    if (!_open) return false;
    // Preferences::isKey é const-incompatível em algumas versões — cast seguro
    return const_cast<Preferences&>(_prefs).isKey(key);
}

void NvsStore::clear() {
    if (_open) _prefs.clear();
}

#else  // NATIVE_BUILD — stubs (use InMemoryStore nos testes)

bool  NvsStore::begin(const char*) { _open = false; return false; }
void  NvsStore::end() {}
void  NvsStore::putFloat(const char*, float) {}
float NvsStore::getFloat(const char*, float def) { return def; }
bool  NvsStore::exists(const char*) const { return false; }
void  NvsStore::clear() {}

#endif
```

- [ ] **Step 3: Compilar para esp32dev**

```bash
pio run -e esp32dev 2>&1 | tail -5
```

Expected: build successful.

- [ ] **Step 4: Verificar que testes nativos não regrediram**

```bash
pio test -e native -f test_velocity_estimator 2>&1 | tail -3
```

Expected: `10 Tests 0 Failures 0 Ignored`

- [ ] **Step 5: Commit**

```bash
git add src/storage/NvsStore.h src/storage/NvsStore.cpp
git commit -m "feat(storage): add ESP32 NVS-backed persistent store"
```

---

## Task B6: Smoke test ESP32 — calibrar e ler RPM

**Files:**
- Create: `examples/velocity_calibration_test.cpp`

- [ ] **Step 1: Criar exemplo**

```cpp
// examples/velocity_calibration_test.cpp
// Procedimento:
//   1. Flash neste arquivo (descomentar no platformio se aplicável)
//   2. Abrir Serial Monitor a 115200
//   3. Quando aparecer "START CAL — gire a roda esquerda 10 voltas e digite f":
//      gire a roda 10 voltas manualmente, depois envie 'f' no Serial.
//   4. Repita para a roda direita.
//   5. Tente girar lentamente e veja RPM no Serial.
#ifndef NATIVE_BUILD
#include <Arduino.h>
#include "config.h"
#include "sensors/Encoder.h"
#include "sensors/VelocityEstimator.h"
#include "storage/NvsStore.h"

static Encoder encL(PIN_ENC_LEFT_A,  PIN_ENC_LEFT_B);
static Encoder encR(PIN_ENC_RIGHT_A, PIN_ENC_RIGHT_B);
static NvsStore nvs;
static VelocityEstimator velL(encL, nvs, "left");
static VelocityEstimator velR(encR, nvs, "right");

static const int ROTATIONS = 10;

static void calibrateAxis(const char* label, VelocityEstimator& ve) {
    Serial.printf("START CAL %s — gire %d voltas e envie 'f'\n", label, ROTATIONS);
    ve.startCalibration();
    while (true) {
        if (Serial.available()) {
            int c = Serial.read();
            if (c == 'f' || c == 'F') break;
        }
        delay(50);
    }
    bool ok = ve.finishCalibration(ROTATIONS);
    Serial.printf("CAL %s: ok=%d, PPR_x4=%.2f\n", label, (int)ok, ve.getEffectivePPR());
}

void setup() {
    Serial.begin(115200);
    delay(500);
    encL.begin();
    encR.begin();
    nvs.begin("lfr");
    velL.begin();
    velR.begin();
    Serial.printf("Loaded PPR L=%.2f R=%.2f\n",
        velL.getEffectivePPR(), velR.getEffectivePPR());
    calibrateAxis("LEFT",  velL);
    calibrateAxis("RIGHT", velR);
    Serial.println("RUN — gire as rodas, leitura a cada 200ms");
}

void loop() {
    static uint32_t last = 0;
    uint32_t now = millis();
    uint32_t dt = now - last;
    last = now;
    velL.update(dt);
    velR.update(dt);
    Serial.printf("rpmL=%.1f  rpmR=%.1f\n", velL.getRPM(), velR.getRPM());
    delay(200);
}
#endif
```

- [ ] **Step 2: Compilar para ESP32**

```bash
pio run -e esp32dev 2>&1 | tail -5
```

Expected: build successful.

- [ ] **Step 3: Commit**

```bash
git add examples/velocity_calibration_test.cpp
git commit -m "test(velocity): add bench smoke test for calibration + live RPM"
```

---

## Critério de "Done" — Fase B

- [ ] `pio test -e native -f test_velocity_estimator` → 10/10 PASSED
- [ ] `pio run -e esp32dev` → SUCCESS
- [ ] PPR salvo em NVS sobrevive a reboot do ESP32 (validar com smoke test em bench)
- [ ] InMemoryStore funciona em testes; NvsStore usado em produção
- [ ] Sem regressão em testes existentes:

```bash
pio test -e native 2>&1 | tail -3
```

Expected: todos os suites passam (test_encoder + test_velocity_estimator + suites pré-existentes).

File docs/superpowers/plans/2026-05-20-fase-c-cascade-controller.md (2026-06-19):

# Fase C — CascadeController Implementation Plan

> **For agentic workers:** REQUIRED SUB-SKILL: Use superpowers:subagent-driven-development (recommended) or superpowers:executing-plans to implement this plan task-by-task. Steps use checkbox (`- [ ]`) syntax for tracking.

**Goal:** Substituir o controle open-loop por uma arquitetura **cascade PID** — o PID externo (posição da linha) gera uma correção em RPM, dois PIDs internos (um por motor) fecham a malha de velocidade com a leitura dos `VelocityEstimator`s. Resultado: robô anda na velocidade comandada independente de carga, atrito ou voltagem.

**Architecture:** `CascadeController` recebe `correction` (saída do PID externo) e `targetBaseRpm` (alvo de velocidade do `SpeedProfile` traduzido para RPM), além das medições atuais `actualRpmL/R` (cliente injeta — desacopla da classe `VelocityEstimator` para facilitar testes). Tradução: `setpointL = base + correction`, `setpointR = base − correction`. Cada PID interno recebe `setpoint − actualRpm` como erro e gera PWM. Saturação: setpoints clamped em `[−maxRpm, +maxRpm]`; PWMs clamped em `[−maxPwm, +maxPwm]`. `main.cpp` é atualizado para instanciar 2× `Encoder`, 2× `VelocityEstimator`, 2× `PIDController` interno + 1× `CascadeController`, e o loop chama na ordem: ler encoders → atualizar estimadores → ler sensores → calcular posição → outer PID → cascade → motors.

**Tech Stack:** C++17, Unity Test Framework, integração com módulos existentes (`PIDController`, `LineFollower`, `SpeedProfile`).

---

## File Map

| File | Action | Purpose |
|---|---|---|
| `src/control/CascadeController.h` | Create | Interface (correction+base+RPM → PWM L/R) |
| `src/control/CascadeController.cpp` | Create | Implementação pura (sem dependência de hardware) |
| `test/test_cascade/test_cascade.cpp` | Create | 8 testes Unity nativos |
| `src/config.h` | Modify | `KP_VEL_DEFAULT`, `KI_VEL_DEFAULT`, `KD_VEL_DEFAULT`, `MAX_RPM_DEFAULT`, `BASE_RPM_DEFAULT` |
| `src/main.cpp` | Modify | Wire up encoders + estimators + cascade no Core 0 loop |

---

## Task C1: Criar testes RED para CascadeController

**Files:**
- Create: `test/test_cascade/test_cascade.cpp`

- [ ] **Step 1: Criar arquivo de teste com 8 testes**

```cpp
// test/test_cascade/test_cascade.cpp
#include <unity.h>
#include "control/CascadeController.h"
#include "control/PIDController.h"

// PIDs internos para os testes — Kp=1, Ki=0, Kd=0 → erro direto vira PWM
// (controlador puramente proporcional simplifica verificações)
static PIDController* innerL = nullptr;
static PIDController* innerR = nullptr;
static CascadeController* cc = nullptr;

void setUp() {
    innerL = new PIDController(1.0f, 0.0f, 0.0f, -1000.0f, 1000.0f, 0.01f);
    innerR = new PIDController(1.0f, 0.0f, 0.0f, -1000.0f, 1000.0f, 0.01f);
    // maxRpm=1000, maxPwm=1023 (10-bit LEDC do ESP32)
    cc = new CascadeController(*innerL, *innerR, 1000.0f, 1023);
}

void tearDown() {
    delete cc;     cc = nullptr;
    delete innerR; innerR = nullptr;
    delete innerL; innerL = nullptr;
}

// ─── 1. Linha reta (correction=0) → setpoints iguais ─────────────────────
void test_cascade_straight_line_equal_setpoints() {
    int pwmL = 0, pwmR = 0;
    // correction=0, base=500, ambos motores parados (rpm=0) → erro=500 cada
    cc->compute(0.0f, 500.0f, 0.0f, 0.0f, pwmL, pwmR);
    TEST_ASSERT_EQUAL_INT(pwmL, pwmR);
    TEST_ASSERT_EQUAL_INT(500, pwmL);
}

// ─── 2. Correção positiva → motor L acelera, motor R desacelera ──────────
void test_cascade_positive_correction_differentiates_motors() {
    int pwmL = 0, pwmR = 0;
    // correction=+100, base=500 → setL=600, setR=400 (ambos rpm=0)
    cc->compute(100.0f, 500.0f, 0.0f, 0.0f, pwmL, pwmR);
    TEST_ASSERT_TRUE(pwmL > pwmR);
    TEST_ASSERT_EQUAL_INT(600, pwmL);
    TEST_ASSERT_EQUAL_INT(400, pwmR);
}

// ─── 3. Motor atingiu setpoint → PWM cai a zero ──────────────────────────
void test_cascade_motor_at_setpoint_outputs_zero() {
    int pwmL = 0, pwmR = 0;
    // setpoint=500, actualRpm=500 → erro=0 → pwm=0
    cc->compute(0.0f, 500.0f, 500.0f, 500.0f, pwmL, pwmR);
    TEST_ASSERT_EQUAL_INT(0, pwmL);
    TEST_ASSERT_EQUAL_INT(0, pwmR);
}

// ─── 4. Motor mais lento que setpoint → PWM positivo ─────────────────────
void test_cascade_slow_motor_gets_positive_pwm() {
    int pwmL = 0, pwmR = 0;
    // setpoint=500, actual=200 → erro=300 → pwm=300
    cc->compute(0.0f, 500.0f, 200.0f, 500.0f, pwmL, pwmR);
    TEST_ASSERT_EQUAL_INT(300, pwmL);
    TEST_ASSERT_EQUAL_INT(0, pwmR);
}

// ─── 5. Setpoint > maxRpm → clamp em maxRpm ──────────────────────────────
void test_cascade_setpoint_clamped_to_max_rpm() {
    int pwmL = 0, pwmR = 0;
    // base=1500 (> maxRpm=1000), correction=0 → setpoint clamped em 1000
    cc->compute(0.0f, 1500.0f, 0.0f, 0.0f, pwmL, pwmR);
    TEST_ASSERT_EQUAL_INT(1000, pwmL);
    TEST_ASSERT_EQUAL_INT(1000, pwmR);
}

// ─── 6. Setpoint negativo → motor em reverso ─────────────────────────────
void test_cascade_negative_setpoint_drives_reverse() {
    int pwmL = 0, pwmR = 0;
    // base=300, correction=+500 → setL=800, setR=-200 (R inverte)
    cc->compute(500.0f, 300.0f, 0.0f, 0.0f, pwmL, pwmR);
    TEST_ASSERT_EQUAL_INT(800, pwmL);
    TEST_ASSERT_EQUAL_INT(-200, pwmR);
}
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

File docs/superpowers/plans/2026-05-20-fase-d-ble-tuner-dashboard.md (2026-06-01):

# Fase D — BLE Tuner Expandido + Dashboard com RPM Implementation Plan

> **For agentic workers:** REQUIRED SUB-SKILL: Use superpowers:subagent-driven-development (recommended) or superpowers:executing-plans to implement this plan task-by-task. Steps use checkbox (`- [ ]`) syntax for tracking.
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

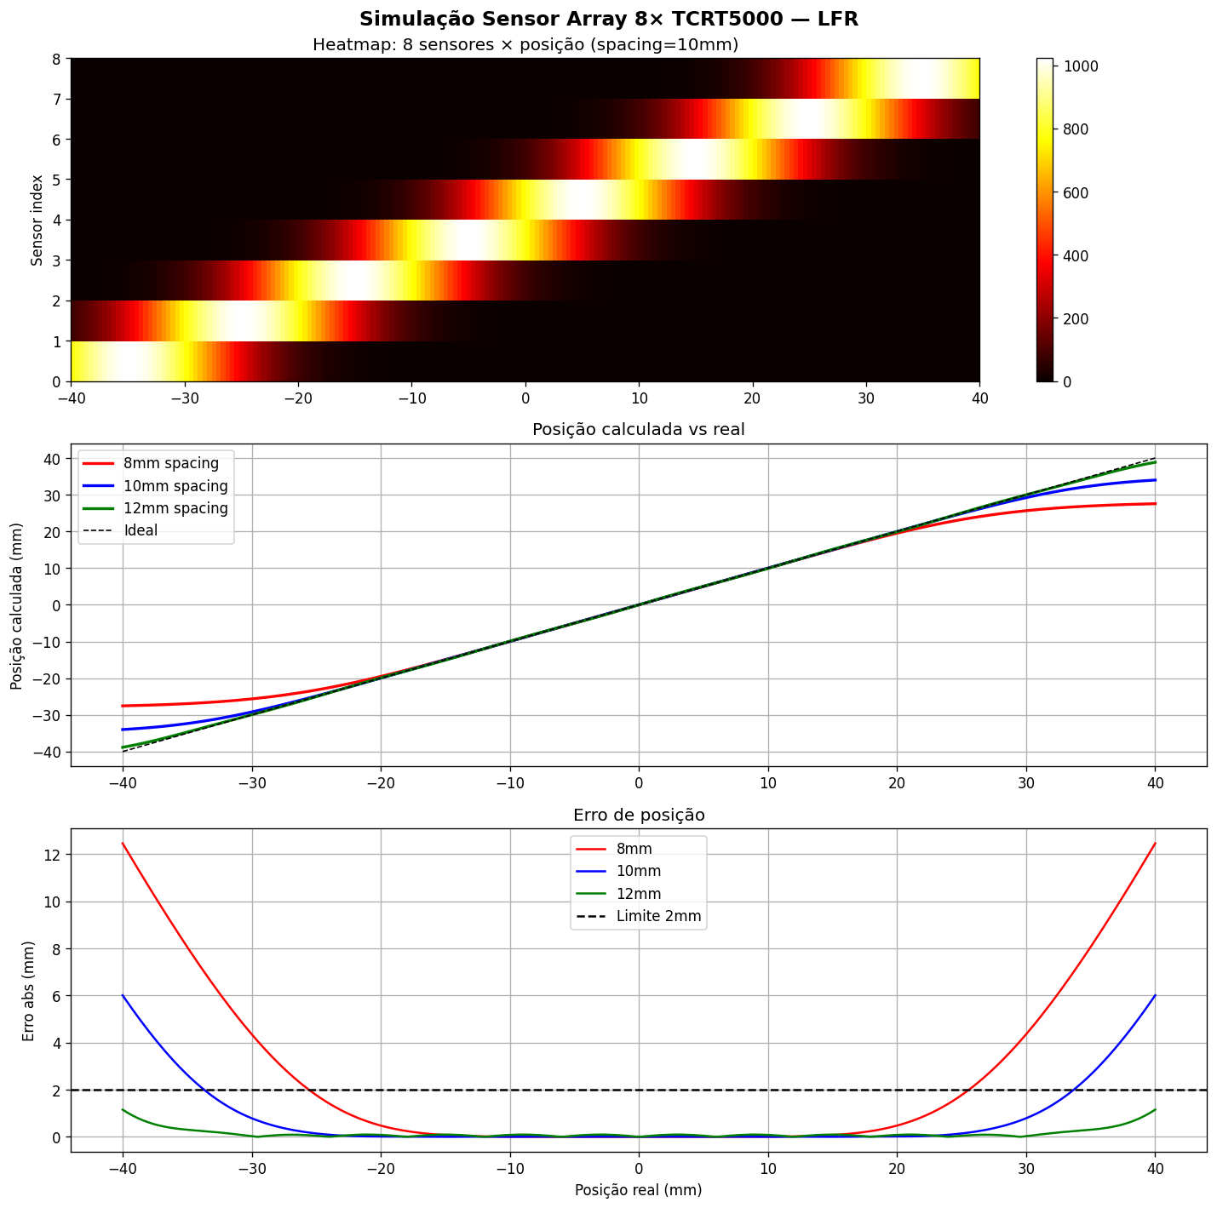
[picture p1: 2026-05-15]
docs/simulations/sensor_linearity.png

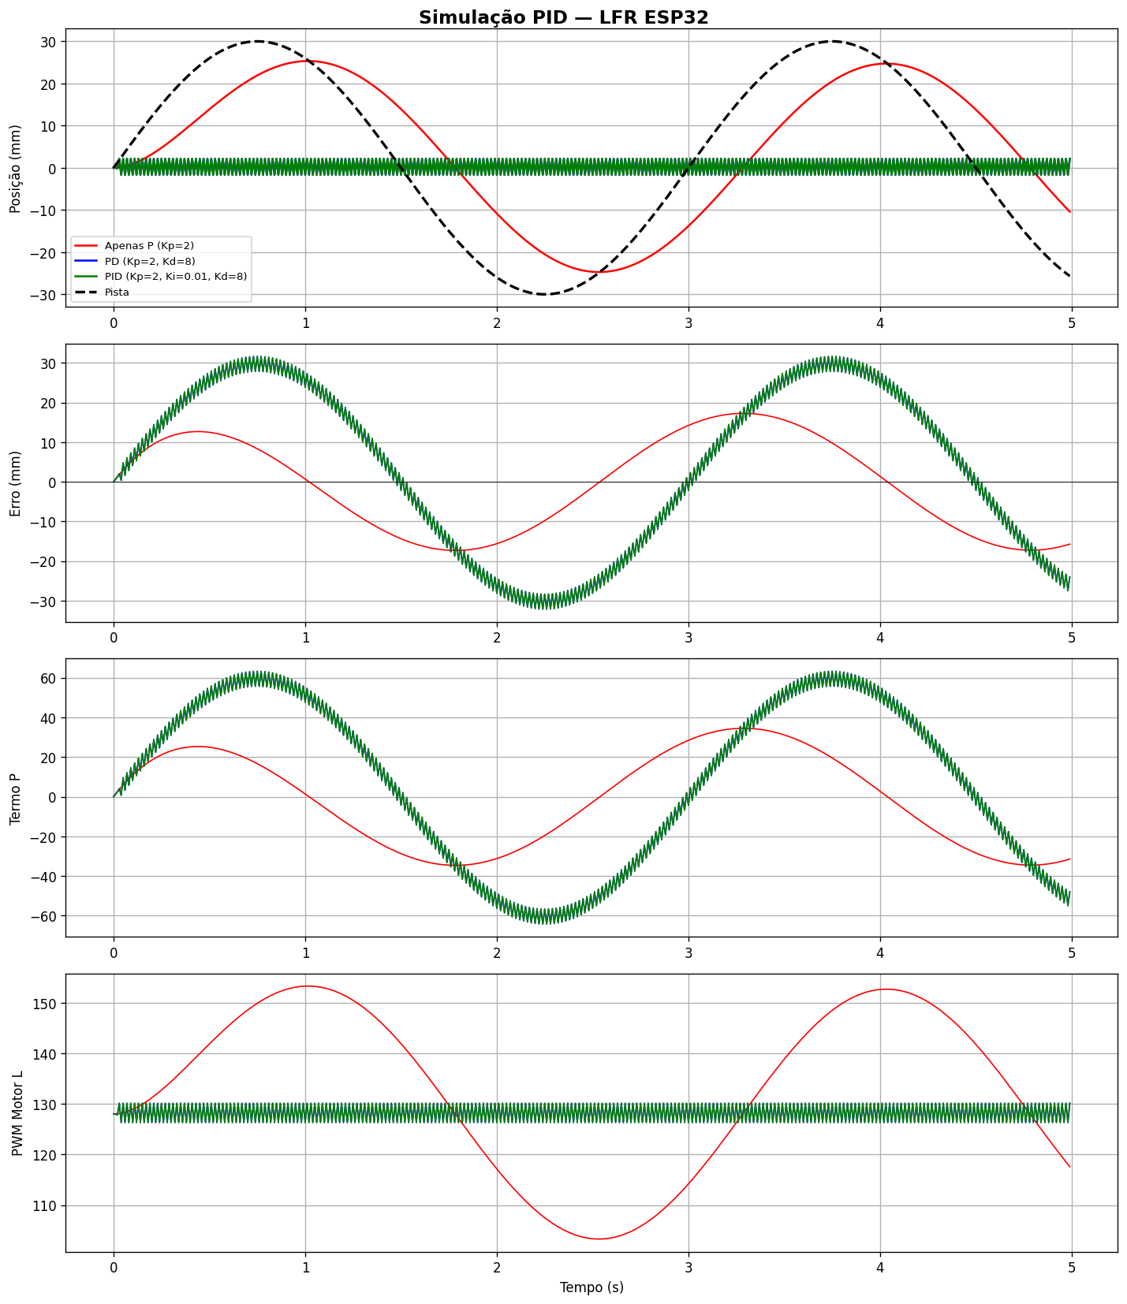
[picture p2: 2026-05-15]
docs/simulations/pid_response.png

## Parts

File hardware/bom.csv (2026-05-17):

qty | component | description | package | supplier | sku | price_brl | link | notes
1 | ESP32 DevKit V1 | MCU dual-core 240 MHz WiFi/BT | DIP-38 | Mercado Livre / AliExpress | ESP32-DEVKITV1 | 45.00 | https://www.mercadolivre.com.br/placa-de-desenvolvimento-esp32-devkit-v1/p/MLB26003803 | Clone WROOM-32 funciona igual
1 | MCP3008 | ADC SPI 8 canais 10-bit | DIP-16 | Mercado Livre / Robocore | MCP3008-I/P | 25.00 | https://www.robocore.net/microcontroladores/conversor-adc-mcp3008-10-bits-8-canais | 1 MHz @ 5V; usar divisor de tensão MISO → 3.3V
1 | TCRT5000 array 8 canais | Sensor IR linha 8× TCRT5000 com ajuste | PCB módulo | Mercado Livre / AliExpress | TCRT5000-8CH | 40.00 |  | Espaçamento ~10 mm; verificar tensão de operação 5V
2 | N20 600RPM c/ encoder | Motor DC metal-gear 6V com encoder Hall 7 PPR | N20 3×10mm shaft | Pololu / AliExpress | 3081 (Pololu) | 80.00 | https://www.pololu.com/product/3081 | Par engrenado; obrigatório com encoder para odometria futura
1 | TB6612FNG módulo | Driver dual H-bridge 1.2A cont / 3.2A pico | módulo PCB | Sparkfun / Mercado Livre | ROB-14450 | 18.00 | https://www.sparkfun.com/products/14450 | Eficiência 95%; STBY com pull-down
1 | LiPo 2S 800mAh 30C | Bateria 7.4V 30C conector JST XT30 | pouch cell | Hobbyking / Mercado Livre | HXT 2S 800-30C | 55.00 |  | Checar dimensões: máx 65×35×12 mm para encaixar no chassi
1 | Carregador B3 2S/3S | Carregador balanceado LiPo 2S/3S AC | — | Mercado Livre / AliExpress | B3AC | 35.00 |  | Não deixar sem supervisão carregando
1 | MP1584 buck converter | Regulador abaixador ajustável até 3A | módulo PCB | Mercado Livre / AliExpress | MP1584EN | 8.00 |  | Ajustar para 5.0V antes de conectar; verificar ripple
1 | Roda silicone 34mm | Roda com pneu silicone D=34mm eixo 3mm plano | — | AliExpress / Mercado Livre |  | 20.00 |  | Par (2 rodas); eixo D-shape 3mm
1 | Ball caster metálico | Roda de apoio traseira ajustável em altura | — | Robocore / Mercado Livre | ROB-09259 | 8.00 | https://www.robocore.net/robotica/bola-de-rodinha-metalica-1-2-polegada | 1/2 pol (12.7 mm); ajustar altura com espaçadores M3
1 | PETG filamento 100g | Impressão 3D chassi e suportes (PETG laranja) | 1.75mm rolo ~100g | Multilaser / Kalatec |  | 25.00 |  | PETG: resistência ao calor e impacto > PLA; densidade ~1.27 g/cm³
1 | Capacitor 100µF 16V | Desacoplamento bateria VCC motors | radial electrolítico | Qualquer distribuidora |  | 2.00 |  | 1× na entrada VCC motores
4 | Capacitor 100nF | Desacoplamento VCC digital | cerâmico 0805 |  |  |  | 3.00 |  | 1× por CI (MCP3008 + ESP32 + TB6612FNG + regulador)
1 | Resistor 100kΩ 1/4W | Divisor tensão VBAT (R1) | — |  |  |  | 0.50 |  | Ver WIRING.md: divisor 100k+47k para GPIO 34
1 | Resistor 47kΩ 1/4W | Divisor tensão VBAT (R2) | — |  |  |  | 0.50
2 | Resistor 10kΩ 1/4W | Pull-down STBY e outros | — |  |  |  | 0.50
1 | Buzzer 5V passivo 12mm | Feedback sonoro | THT 12mm |  |  |  | 2.00 |  | Passivo (tone() do Arduino); ativo também funciona
1 | LED 5mm (verde + vermelho) | Indicação de status | THT 5mm |  |  |  | 1.50 |  | 1 verde (READY) + 1 vermelho (ERROR) ou 1 bicolor
2 | Resistor 330Ω 1/4W | Serie para LEDs | — |  |  |  | 0.50
1 | Chave SPDT mini | Liga/desliga geral | — |  |  |  | 3.00 |  | Corrente mínima 2A para LiPo 2S
1 | Conector JST XH 2.54mm | Conector bateria LiPo | 2-pin JST XT30 ou XH |  |  |  | 2.00 |  | Combinar com o conector da bateria
1 | Perfboard 5×7 cm | PCB universal para montagem | — |  |  |  | 6.00 |  | Alternativa: PCB shield ESP32 (arquivo KiCad em hardware/pcb/)
1 | Fios silicone 26 AWG | Cabagem geral (sortido 5 cores 50cm) | — |  |  |  | 15.00 |  | Silicone suporta dobramento repetido
1 | Parafusos M2×8 (kit 20un) | Fixação sensores e motores N20 | M2 chave hex |  |  |  | 5.00
1 | Parafusos M3×10 (kit 20un) | Fixação chassi e suportes | M3 chave hex |  |  |  | 5.00
1 | Porcas M2 (kit 20un) | Par para parafusos M2 | M2 |  |  |  | 2.00
1 | Porcas M3 (kit 20un) | Par para parafusos M3 | M3 |  |  |  | 2.00
1 | Espaçadores M3×5mm (kit 10un) | Separar PCB do chassi | alumínio/nylon M3 |  |  |  | 5.00
1 | Fita dupla-face 3M VHB | Fixação bateria e PCB | — |  |  |  | 8.00 |  | Alternativa: velcro para trocar bateria rápido
1 | Kit O-rings silicone 34mm | Pneu extra para rodas (reserva) | — |  |  |  | 5.00 |  | Espessura ~2 mm; comprar 2 extras
 | TOTAL ESTIMADO (R$) |  |  |  |  |  | 423.00

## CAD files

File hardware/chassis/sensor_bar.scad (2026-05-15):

// sensor_bar.scad — Barra de sensores LFR (8× TCRT5000 / QRE1113)
// Fatiamento: PETG, 0.15mm camada, 50% infill, 4 perímetros
// Montagem: parafusos M2 × 6mm nos sensores, M3 no suporte vertical
// Rafael Costa — LFR ESP32

// ═══ PARÂMETROS ══════════════════════════════════════════════════════════════
SENSOR_COUNT    = 8;
SENSOR_SPACING  = 10;     // mm — centro a centro
SENSOR_W        = 5.5;    // mm — largura do corpo TCRT5000
SENSOR_H        = 5.5;    // mm — altura do corpo
SENSOR_T        = 1.8;    // mm — profundidade (plana no PCB)
SENSOR_DEPTH    = 4;      // mm — altura do solo ao sensor (spec)

BAR_THICK       = 3;      // mm — espessura da barra
BAR_HEIGHT      = 8;      // mm — altura total da barra
BAR_EXTRA       = 10;     // mm — extensão além dos sensores externos

MOUNT_H         = 40;     // mm — altura do suporte vertical até o chassi
MOUNT_W         = 12;     // mm — largura do suporte
MOUNT_SLOT_W    = 4;      // mm — slot de ajuste de altura (±5mm)

CABLE_CHANNEL_W = 8;      // mm — canal para flat cable/fios
CABLE_CHANNEL_H = 3;

TOL = 0.25;

// ═══ MÓDULOS ═════════════════════════════════════════════════════════════════

module sensorPocket() {
    // Encaixe para TCRT5000 — desliza pelo topo
    cube([SENSOR_W + TOL*2,
          SENSOR_T + TOL,
          SENSOR_H + 1]);
}

module m2Hole() {
    cylinder(d=2.4, h=20, $fn=20);
}

module m3Hole() {
    cylinder(d=3.4, h=30, $fn=20);
}

module slotHole(w, h, l) {
    // Slot oblongo para ajuste
    hull() {
        cylinder(d=w, h=l, $fn=20);
        translate([0, h, 0]) cylinder(d=w, h=l, $fn=20);
    }
}

// ═══ BARRA PRINCIPAL ════════════════════════════════════════════════════════

module sensorBar() {
    BAR_TOTAL = (SENSOR_COUNT - 1) * SENSOR_SPACING + SENSOR_W + BAR_EXTRA * 2;
    START_X   = BAR_EXTRA;

    difference() {
        // Corpo da barra
        translate([0, 0, 0])
            cube([BAR_TOTAL, BAR_THICK, BAR_HEIGHT]);

        // Pockets dos sensores (abertos pelo fundo para apontar ao solo)
        for (i = [0 : SENSOR_COUNT - 1]) {
            translate([START_X + i * SENSOR_SPACING - TOL,
                       BAR_THICK - SENSOR_T - TOL,
                       1])
                sensorPocket();
        }

        // Furos M2 de fixação dos sensores
        for (i = [0 : SENSOR_COUNT - 1]) {
            translate([START_X + i * SENSOR_SPACING + SENSOR_W/2,
                       -1,
                       BAR_HEIGHT / 2])
                rotate([-90, 0, 0])
                    m2Hole();
        }

        // Canal de cabos (topo da barra, centralizado)
        translate([(BAR_TOTAL - CABLE_CHANNEL_W) / 2,
                   -1,
                   BAR_HEIGHT - CABLE_CHANNEL_H - 1])
            cube([CABLE_CHANNEL_W, BAR_THICK + 2, CABLE_CHANNEL_H + 1]);
    }
}

// ═══ SUPORTE VERTICAL ═══════════════════════════════════════════════════════

module mountArm() {
    BAR_TOTAL = (SENSOR_COUNT - 1) * SENSOR_SPACING + SENSOR_W + BAR_EXTRA * 2;
    ARM_X     = BAR_TOTAL / 2 - MOUNT_W / 2;

    difference() {
        union() {
            // Haste vertical
            translate([ARM_X, 0, BAR_HEIGHT])
                cube([MOUNT_W, BAR_THICK, MOUNT_H]);

            // Reforço triangular (evita flex)
            translate([ARM_X, 0, BAR_HEIGHT])
                rotate([0, 0, 0])
                linear_extrude(height=BAR_THICK)
                    polygon([[0,0],
                             [MOUNT_W, 0],
                             [MOUNT_W, MOUNT_H * 0.4],
                             [0, MOUNT_H * 0.4]]);
        }

        // Slot de ajuste de altura (M3) no topo do suporte
        translate([ARM_X + MOUNT_W/2,
                   BAR_THICK/2,
                   BAR_HEIGHT + MOUNT_H - 5])
            rotate([90, 0, 0])
                slotHole(3.4, 10, BAR_THICK + 2);
    }
}

// ═══ RENDER ══════════════════════════════════════════════════════════════════
// Para exportar STL: openscad -o sensor_bar.stl sensor_bar.scad
sensorBar();
mountArm();

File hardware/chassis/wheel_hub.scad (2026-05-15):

// wheel_hub.scad — Hub de roda para O-ring silicone 34mm OD
// Fatiamento: PETG, 0.15mm camada, 60% infill, 4 perímetros, sem suporte
// Eixo N20: 3mm × D achatado — usar flat do motor para anti-giro
// Rafael Costa — LFR ESP32

// ═══ PARÂMETROS ══════════════════════════════════════════════════════════════
// Roda
WHEEL_OD      = 34;    // mm — diâmetro externo (O-ring silicone)
WHEEL_WIDTH   = 8;     // mm — largura total do hub
ORING_GROOVE_D = 30;   // mm — diâmetro do fundo do canal do O-ring
ORING_GROOVE_W = 3.5;  // mm — largura do canal (O-ring 3mm seção)
ORING_GROOVE_D_ORING = 3; // mm — seção do O-ring

// Eixo N20 (3mm, achatado em D)
AXLE_D        = 3.0;   // mm — diâmetro total
AXLE_FLAT     = 2.5;   // mm — distância flat→ centro (corte D)
AXLE_DEPTH    = 10;    // mm — profundidade do furo de encaixe

// Hub
HUB_D         = 14;    // mm — diâmetro do cubo central
HUB_SPOKE_W   = 3;     // mm — largura dos raios
SPOKE_COUNT   = 5;     // raios

// Fixação extra
GRUB_D        = 3.0;   // mm — furo para parafuso M3 grub (anti-rotação)
GRUB_DEPTH    = 8;     // mm

TOL = 0.2;

// ═══ MÓDULOS ═════════════════════════════════════════════════════════════════

module dShaft(d, flat, depth) {
    // Furo em D para eixo N20
    difference() {
        cylinder(d=d + TOL*2, h=depth + 1, $fn=32);
        // Remove excesso para criar flat
        translate([-d, flat - d/2, -1])
            cube([d*2, d, depth + 3]);
    }
}

module oringGroove() {
    // Canal toroidal para O-ring silicone
    rotate_extrude($fn=128)
        translate([ORING_GROOVE_D/2, WHEEL_WIDTH/2, 0])
            circle(d=ORING_GROOVE_D_ORING + TOL, $fn=32);
}

module spoke() {
    // Raio trapezoidal (mais largo na borda)
    linear_extrude(height=WHEEL_WIDTH)
        polygon([
            [-HUB_SPOKE_W/2, HUB_D/2],
            [ HUB_SPOKE_W/2, HUB_D/2],
            [ HUB_SPOKE_W*1.5, ORING_GROOVE_D/2 - 2],
            [-HUB_SPOKE_W*1.5, ORING_GROOVE_D/2 - 2]
        ]);
}

// ═══ ASSEMBLY ════════════════════════════════════════════════════════════════

module wheelHub() {
    difference() {
        union() {
            // Aro externo
            difference() {
                cylinder(d=WHEEL_OD, h=WHEEL_WIDTH, $fn=128);
                translate([0, 0, -1])
                    cylinder(d=ORING_GROOVE_D - ORING_GROOVE_D_ORING, h=WHEEL_WIDTH+2, $fn=128);
            }

            // Cubo central
            cylinder(d=HUB_D, h=WHEEL_WIDTH, $fn=64);

            // Raios
            for (i = [0 : SPOKE_COUNT - 1])
                rotate([0, 0, i * 360 / SPOKE_COUNT])
                    spoke();
        }

        // Canal O-ring
        oringGroove();

        // Furo do eixo em D (passante, centro)
        translate([0, 0, -1])
            dShaft(AXLE_D, AXLE_FLAT, AXLE_DEPTH + 1);

        // Furo grub screw M3 (perpendicular ao eixo, no cubo)
        translate([HUB_D/2 + 1, 0, AXLE_DEPTH/2])
            rotate([0, -90, 0])
                cylinder(d=GRUB_D, h=GRUB_DEPTH, $fn=20);
    }
}

// ═══ RENDER ══════════════════════════════════════════════════════════════════
// Para exportar STL: openscad -o wheel_hub.stl wheel_hub.scad
// Imprimir 2× (roda L + roda R — simétricas)
wheelHub();

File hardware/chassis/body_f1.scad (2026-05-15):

// body_f1.scad — Chassis principal LFR formato F1 paramétrico
// Fatiamento: PETG, 0.2mm camada, 40% infill, 3 perímetros, suporte não necessário
// Dimensões máx competição: 250×250×200mm
// Rafael Costa — LFR ESP32

// ═══ PARÂMETROS ══════════════════════════════════════════════════════════════
// Corpo principal
BODY_LENGTH   = 180;   // mm — frente a trás
BODY_WIDTH    = 120;   // mm — largura total
BODY_HEIGHT   = 12;    // mm — espessura do piso
WALL          = 2.4;   // mm — espessura de parede (3 × 0.8mm bico)

// Recortes de componentes
ESP32_L       = 52;    // mm — ESP32 DevKit V1
ESP32_W       = 29;    // mm
ESP32_MARGIN  = 1.5;   // mm — folga por lado

LIPO_L        = 58;    // mm — LiPo 2S 800mAh
LIPO_W        = 32;
LIPO_H        = 12;

PCB_L         = 50;    // mm — perfboard shield
PCB_W         = 70;

// Motores N20
MOTOR_D       = 12;    // mm — diâmetro corpo motor
MOTOR_L       = 25;    // mm — comprimento
MOTOR_OFFSET  = 10;    // mm — recuo do eixo à traseira
MOTOR_SPACING = 80;    // mm — distância entre eixos L/R (center-to-center)

// Roda
WHEEL_D       = 34;    // mm — diâmetro silicone
WHEEL_W       = 8;     // mm — largura
AXLE_D        = 3;     // mm — diâmetro eixo

// Ball caster
CASTER_D      = 15;    // mm — esfera metálica
CASTER_POS_X  = BODY_LENGTH * 0.75;  // posição longitudinal (da frente)

// Sensor bar
SENSOR_BAR_L      = 90;   // mm — barra de sensores (8 × 10mm espaçamento)
SENSOR_BAR_OFFSET = 15;   // mm — avanço à frente do corpo
SENSOR_BAR_DROP   = 40;   // mm — profundidade do suporte vertical
SENSOR_HEIGHT     = 4;    // mm — altura do solo ao sensor

// Tolerância de impressão
TOL = 0.3;

// ═══ MÓDULOS ═════════════════════════════════════════════════════════════════

module roundedRect(l, w, h, r=3) {
    hull() {
        for (x = [r, l-r])
        for (y = [r, w-r])
            translate([x, y, 0]) cylinder(h=h, r=r, $fn=32);
    }
}

module motorCutout() {
    cylinder(d=MOTOR_D + TOL*2, h=MOTOR_L + 5, $fn=32);
}

module esp32Slot() {
    cube([ESP32_L + ESP32_MARGIN*2,
          ESP32_W + ESP32_MARGIN*2,
          BODY_HEIGHT + 1]);
}

module lipoBay() {
    cube([LIPO_L + TOL*2, LIPO_W + TOL*2, LIPO_H + TOL]);
}

module screwHole(d=3.2, h=20) {
    cylinder(d=d, h=h, $fn=24);
}

module screwBoss(d_outer=8, d_inner=3.2, h=6) {
    difference() {
        cylinder(d=d_outer, h=h, $fn=32);
        cylinder(d=d_inner, h=h+1, $fn=24);
    }
}

// ═══ CORPO PRINCIPAL ════════════════════════════════════════════════════════

module body() {
    difference() {
        // Piso principal — perfil F1: largo na traseira, estreito na frente
        hull() {
            // Traseira larga
            translate([0, 0, 0])
                roundedRect(BODY_WIDTH * 0.9, BODY_LENGTH * 0.45, BODY_HEIGHT, r=5);
            // Frente estreita
            translate([BODY_WIDTH * 0.1, BODY_LENGTH * 0.45, 0])
                roundedRect(BODY_WIDTH * 0.8, BODY_LENGTH * 0.55, BODY_HEIGHT, r=3);
        }

        // Recorte ESP32 (centro, traseira)
        translate([(BODY_WIDTH - ESP32_L - ESP32_MARGIN*2) / 2,
                   BODY_LENGTH * 0.05,
                   BODY_HEIGHT - 8])
            esp32Slot();

        // Recorte LiPo (centro, meio do chassi)
        translate([(BODY_WIDTH - LIPO_L - TOL*2) / 2,
                   BODY_LENGTH * 0.35,
                   BODY_HEIGHT - LIPO_H])
            lipoBay();

        // Furos dos motores N20 (sides)
        for (side = [-1, 1]) {
            translate([BODY_WIDTH/2 + side * MOTOR_SPACING/2,
                       BODY_LENGTH - MOTOR_OFFSET,
                       BODY_HEIGHT/2])
                rotate([0, 90, 0])
                    motorCutout();
        }

        // Furo ball caster (frente)
        translate([BODY_WIDTH/2, CASTER_POS_X, -1])
            cylinder(d=CASTER_D + TOL*2, h=BODY_HEIGHT+2, $fn=32);

        // Slot suporte barra de sensores
        translate([BODY_WIDTH/2 - 6, BODY_LENGTH - 3, 0])
            cube([12, WALL + 1, BODY_HEIGHT]);

        // Ventilação TB6612 / buck (furos 5mm em grid)
        for (x = [0:10:30], y = [0:10:30])
            translate([BODY_WIDTH*0.6 + x, BODY_LENGTH*0.5 + y, -1])
                cylinder(d=5, h=BODY_HEIGHT+2, $fn=16);
    }

    // Bosses M3 para montagem de PCB (4 cantos)
    for (x = [15, BODY_WIDTH - 15])
    for (y = [BODY_LENGTH*0.45, BODY_LENGTH*0.75])
        translate([x, y, BODY_HEIGHT])
            screwBoss(d_outer=7, d_inner=3.2, h=4);

    // Parede traseira (guarda bateria)
    translate([WALL, 0, 0])
        cube([BODY_WIDTH - WALL*2, WALL, BODY_HEIGHT + LIPO_H]);
}

// ═══ RENDER ════════════════════════════════════════════════════════════════
// Para exportar STL: openscad -o body_f1.stl body_f1.scad
body();

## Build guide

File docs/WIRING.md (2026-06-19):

# WIRING.md — Diagrama de Fiação LFR ESP32

## Visão Geral

```
LiPo 2S 7.4V
    │
    ├─── MP1584 buck ──► 5V ──► ESP32 VIN ──► (LDO onboard) ──► 3V3 pin
    │                                              └► MCP3008 VDD/VREF + QTR-8A VCC (3.3V)
    │
    └─── TB6612FNG VM (7.4V direto)
```

---

## Pinagem ESP32 DevKit V1

### SPI → MCP3008

| ESP32 GPIO | MCP3008 | Descrição |
|---|---|---|
| GPIO 13 (MOSI) | DIN (pin 11) | Dados para ADC |
| GPIO 12 (MISO) | DOUT (pin 12) | Dados do ADC |
| GPIO 14 (CLK)  | CLK (pin 13) | Clock SPI |
| GPIO 15 (CS) | CS/SHDN (pin 10) | Chip Select ativo-baixo |
| 3V3 | VDD + VREF (pin 16 + 15) | Alimentação e referência |
| GND | GND (pin 9) | Terra |

**Configuração MCP3008:**
- Modo single-ended: 8 canais (CH0–CH7), um sensor por canal
- SPI @ 1 MHz, modo 0,0
- Resolução: 10 bits (0–1023)

### Motores → TB6612FNG

| ESP32 GPIO | TB6612FNG | Descrição |
|---|---|---|
| GPIO 25 (PWM-A) | PWMA | PWM motor esquerdo |
| GPIO 26 | AIN1 | Direção A bit 1 |
| GPIO 27 | AIN2 | Direção A bit 2 |
| GPIO 33 (PWM-B) | PWMB | PWM motor direito |
| GPIO 32 | BIN1 | Direção B bit 1 |
| GPIO 4  | BIN2 | Direção B bit 2 |
| GPIO 23 | STBY | Standby (HIGH = ativo) |
| 5V | VCC | Lógica do driver |
| LiPo+ | VM | Motor supply (7.4V) |
| GND | GND | Terra |

**Modos de operação TB6612:**

| IN1 | IN2 | PWM | Modo |
|-----|-----|-----|---|
| H | L | PWM | Forward |
| L | H | PWM | Reverse |
| H | H | – | Brake |
| L | L | – | Coast |

### N20 Motores + Encoders Hall — Quadratura 4×

A classe `Encoder` (src/sensors/Encoder.h) lê os 2 canais via interrupt
`CHANGE` em ambos os pinos (4 transições por período do encoder).

| Encoder | ESP32 GPIO | Notas |
|---|---|---|
| Esq. CH-A | GPIO 18 | Pull-up interno (INPUT) |
| Esq. CH-B | GPIO 19 | Pull-up interno (INPUT) |
| Dir. CH-A | GPIO 36 (VP) | Input-only, **pull-up 10kΩ externo obrigatório** |
| Dir. CH-B | GPIO 39 (VN) | Input-only, **pull-up 10kΩ externo obrigatório** |

> ⚠️ **HARDWARE CHECKLIST OBRIGATÓRIO** — GPIO 36 e 39 são input-only RTC pins
> sem pull-up interno. `pinMode(36, INPUT_PULLUP)` é silenciosamente ignorado
> pelo HAL do Arduino-ESP32; o firmware usa `pinMode(36, INPUT)` para deixar
> isso explícito. **Sem o resistor 10kΩ externo entre o pino e VCC, os pinos
> ficam flutuando e o ISR dispara em ruído elétrico, "girando" o contador
> sozinho e destruindo a estabilidade do PID interno.**

```
VCC (3.3V) ─── 10kΩ ─── GPIO 36 ─── Encoder Dir CH-A
VCC (3.3V) ─── 10kΩ ─── GPIO 39 ─── Encoder Dir CH-B
```

### Controles e Sensores Auxiliares

| ESP32 GPIO | Componente | Notas |
|---|---|---|
| GPIO 0 | Botão START/CAL | Pull-up interno; LOW = pressionado |
| GPIO 22 | Buzzer passivo | PWM tone para feedback |
| GPIO 2 | LED status onboard | HIGH = aceso |
| GPIO 34 | Divisor VBAT | 100kΩ / 47kΩ → ESP32 (input-only) |

**Divisor de tensão VBAT:**
```
LiPo+ ─── 100kΩ ─── GPIO34 ─── 47kΩ ─── GND
Tensão no GPIO = Vbat × 47 / (100+47) = Vbat × 0.32
2S full (8.4V) → GPIO34 = 2.69V ✓ (< 3.3V)
2S empty (6.0V) → GPIO34 = 1.92V
```

---

## Array de Sensores — Pololu QTR-8A (analógico)

8 sensores em linha (passo 9,525 mm), saídas analógicas lidas pelo MCP3008.
A placa QTR-8A já traz os LEDs IR, fototransistores e pull-ups embutidos — basta
alimentar e ligar as 8 saídas ao ADC. **Não há resistores discretos a montar.**

```
QTR-8A  OUT1 OUT2 OUT3 OUT4 OUT5 OUT6 OUT7 OUT8
         │    │    │    │    │    │    │    │
MCP3008  CH0  CH1  CH2  CH3  CH4  CH5  CH6  CH7
              │  SPI  │
           ESP32 GPIO 12-15
```

| QTR-8A | Liga em | Notas |
|---|---|---|
| VCC | **3.3V** | jumper/seleção da placa em 3.3V — casa com VREF do MCP3008 |
| GND | GND | terra comum |
| OUT1–OUT8 | MCP3008 CH0–CH7 | uma saída analógica por canal |
| LEDON | (deixar solto) | pull-up interno mantém os emissores ligados |

> ⚠️ **Alimente o QTR-8A em 3.3V, não 5V.** O MCP3008 opera com VDD/VREF = 3.3V;
> a 5V as saídas do array chegariam a ~5V e excederiam a tensão de entrada do ADC
> (máx VDD+0,3V), além de perder faixa útil. Em 3.3V a saída varia 0–3.3V → faixa
> cheia e segura.

> ℹ️ O passo físico do QTR-8A é 9,525 mm; `config.h` usa `SENSOR_SPACING_MM 10`.
> A diferença (~5%) é cosmética — apenas escala a magnitude do erro, absorvida pelo
> Kp e pela calibração min/max por canal.

Saída analógica: tensão **alta** sobre preto (baixa reflexão), **baixa** sobre a
linha branca (alta reflexão). A classe `Calibration` aprende min/max por canal,
então a polaridade é normalizada automaticamente.

---

## Alimentação

```
LiPo 2S 7.4V ──┬── MP1584 buck ── 5V ──┬── ESP32 VIN ──► 3V3 pin ─┬─ MCP3008 VDD/VREF
               │                       │                          └─ QTR-8A VCC
               │                       └── TB6612FNG VCC (lógica)
               │
               └── TB6612FNG VM (direto 7.4V)

Capacitores de desacoplamento:
  100µF × 1 → LiPo+ / GND (perto do TB6612)
  100nF × 4 → VCC / GND de cada IC
```

**Consumo estimado:**

| Componente | Corrente |
|---|---|
| ESP32 (WiFi off) | ~80 mA |
| 2× N20 em carga | ~400 mA |
| QTR-8A (8 emissores) | ~100 mA |
| MCP3008 | ~1 mA |
| **Total** | **~600 mA** |

LiPo 800mAh / 600mA ≈ **~8 min** de autonomia em corrida.

---

## Chave Liga/Desliga

Inserir chave SPDT em série no positivo do LiPo, antes de qualquer divisão de alimentação. Posicionar acessível no chassis sem precisar abrir a carroceria.

---

## Diagrama ASCII

```
               ┌─────────────────────────────────────┐
               │          ESP32 DevKit V1             │
               │                                     │
         ┌─────┤ GPIO13 MOSI   GPIO25 PWM-A ├─────┐
         │     │ GPIO12 MISO   GPIO26 AIN1  │     │
    MCP3008     │ GPIO14 CLK    GPIO27 AIN2  │  TB6612FNG
    8ch ADC     │ GPIO15 CS     GPIO33 PWM-B │     │
         └─────┤               GPIO32 BIN1  ├─────┘
               │               GPIO 4 BIN2  │
               │               GPIO23 STBY  │
               │                            │
               │ GPIO18 ENC-L-A  GPIO 0 BTN │
               │ GPIO19 ENC-L-B  GPIO22 BUZ │
               │ GPIO36 ENC-R-A  GPIO 2 LED │
               │ GPIO39 ENC-R-B  GPIO34 BAT │
               └─────────────────────────────────────┘
                    │             │
               N20 Esq.       N20 Dir.
               + Encoder      + Encoder
```

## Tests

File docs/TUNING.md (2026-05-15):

# TUNING.md — Procedimento de Ajuste PID

## Visão Geral

O ajuste fino do PID é a diferença entre um robô que segue a linha e um campeão. Este documento descreve o procedimento sistemático de calibração, desde o zero absoluto até o modo competição.

---

## 1. Antes de Começar

### Checklist de hardware
- [ ] Bateria carregada (> 7.0 V em 2S LiPo)
- [ ] Sensores a **4 mm** do chão (verificar com calibre)
- [ ] Rodas limpas, O-rings sem desgaste
- [ ] Pino STBY habilitado (fio solto = motores mortos)
- [ ] Encoder: pulsos chegando no osciloscópio ou Serial (teste rápido)
- [ ] Dashboard BLE conectado e telemetria fluindo

### Parâmetros de partida (config.h)
```cpp
KP_DEFAULT   = 3.0f
KI_DEFAULT   = 0.0f
KD_DEFAULT   = 12.0f
BASE_SPEED   = 160      // 0-255
MAX_SPEED    = 230
MIN_SPEED    = 60
THRESHOLD    = 0.6f
```

---

## 2. Calibração dos Sensores

### Procedimento obrigatório antes de qualquer tuning
1. Posicionar o robô sobre a pista (linha visível pelos sensores)
2. Pressionar BTN (GPIO 0) — estado muda para `CALIBRATING`
3. Mover o robô **lentamente** de um lado ao outro da linha durante 5 s
4. O LED pisca quando a calibração captura extremos satisfatórios
5. Pressionar BTN novamente → estado `READY`

### Verificar no dashboard
- Todos os 8 sensores devem variar entre 0–1000 (normalizado)
- Sensor sobre linha branca: valor alto (> 700)
- Sensor sobre pista preta: valor baixo (< 200)
- Se algum sensor não varia → checar conexão SPI / MCP3008

---

## 3. Método Ziegler-Nichols Modificado

### Passo 1 — Encontrar Ku (ganho crítico de oscilação)

1. Zerar Ki e Kd via BLE slider (Ki=0, Kd=0)
2. Começar com Kp = 1.0
3. Incrementar Kp em 0.5 a cada tentativa
4. Observar o robô na pista:
   - Kp baixo: robô lento para corrigir, sai da linha em curvas
   - Kp correto: robô oscila com amplitude constante em reta
   - Kp alto demais: oscilação cresce → sai da linha
5. Anotar o Kp onde oscila sem crescer → esse é **Ku**
6. Medir o período de oscilação no gráfico de posição → **Tu** (em ms)

### Passo 2 — Calcular parâmetros iniciais

| Controlador | Kp | Ki | Kd |
|---|---|---|---|
| P | 0.50 × Ku | — | — |
| PD | 0.80 × Ku | — | 0.125 × Tu |
| PID clássico| 0.60 × Ku | 1.2/Tu | 0.075 × Tu |
| PID agressivo| 0.70 × Ku | 1.75/Tu | 0.105 × Tu |

> Para LFR: começar com **PD** (Ki=0). Adicionar Ki só se houver erro estático persistente.

### Passo 3 — Ajuste fino iterativo

```
Iteração 1: definir Kp e Kd por Ziegler-Nichols PD
Iteração 2: aumentar velocidade base em 10 pontos → re-testar
Iteração 3: se oscila em reta → aumentar Kd 10%
Iteração 4: se lento em curva → reduzir MIN_SPEED ou THRESHOLD
Iteração 5: se perde linha em S → aumentar Kp 15% ou reduzir MAX_SPEED
```

---

## 4. Guia de Sintomas e Correções

| Sintoma | Causa provável | Ação |
|---|---|---|
| Oscila em reta mesmo em baixa velocidade | Kp alto demais | Reduzir Kp 20% |
| Não segue curva fechada | Kp baixo, MIN_SPEED alto | Aumentar Kp, reduzir MIN_SPEED |
| Atraso visível na resposta | Kd baixo ou loop > 2 ms | Aumentar Kd, verificar timing |
| Erro estático (desvia da linha gradualmente) | Ki = 0 com atrito assimétrico | Adicionar Ki = 0.01–0.05 |
| Perde linha no cruzamento | SpeedProfile agressivo | Aumentar THRESHOLD, reduzir MAX_SPEED |
| Vibração nos motores em baixa velocidade | PWM < deadband | Aumentar MIN_SPEED |
| Sai pela esquerda sistematicamente | Sensores descalibrados | Recalibrar; verificar altura |
| Loop > 2 ms | SPI lento ou cálculo pesado | Verificar SPI_FREQ, checar profiler |

---

## 5. SpeedProfile — Ajuste de Velocidade Adaptativa

O `SpeedProfile` reduz velocidade proporcionalmente ao erro absoluto:

```
erro em [0, THRESHOLD]  →  velocidade em [MAX_SPEED, BASE_SPEED]
erro > THRESHOLD        →  velocidade = MIN_SPEED (curva fechada)
```

### Estratégia por estágio de competição

| Fase | BASE | MAX | MIN | THRESHOLD | Objetivo |
|---|---|-----|-----|---|---|
| Aprendizado | 120 | 160 | 60 | 0.8 | Completar percurso |
| Retas | 160 | 200 | 70 | 0.6 | Tempo competitivo |
| Curvas | 150 | 190 | 55 | 0.5 | Precisão nas curvas |
| Competição | 170 | 230 | 60 | 0.55 | Máximo desempenho |

---

## 6. Log de Sessões de Tuning

Registrar cada sessão na planilha `docs/tuning_log.csv`:

```
data,kp,ki,kd,base_speed,max_speed,min_speed,threshold,melhor_volta_s,observacoes
```

---

## 7. Procedimento de Competição (Dia D)

### 30 minutos antes
1. Calibrar sensores na pista oficial (mesma iluminação)
2. Verificar tensão da bateria (7.2–8.4 V)
3. Rodar 3 voltas em modo conservador (BASE=140, MAX=180)
4. Anotar linha de base

### Progressão nas 3 tentativas
- **Tentativa 1**: configuração conservadora → garantir completar
- **Tentativa 2**: aumentar BASE+10, MAX+15 → buscar melhor tempo
- **Tentativa 3**: máximo desempenho configurado em sessão prévia

### Emergências
- **Bateria caindo**: reduzir MAX_SPEED em 20 pts (tensão baixa = torque baixo)
- **Piso escorregadio**: aumentar Kd 15%, reduzir MAX_SPEED
- **Iluminação diferente**: recalibrar sensores obrigatoriamente

---

## 8. Referências

- [Ziegler-Nichols PID Tuning — Wikipedia](https://en.wikipedia.org/wiki/Ziegler%E2%80%93Nichols_method)
- [PID Tuning Guide — Zbotic (LFR específico)](https://zbotic.in/pid-line-follower-robot-tuning-speed-competition/)
- [Semreh V2 — Parâmetros campeão brasileiro](https://hackaday.io/project/202208-semreh-advanced-line-follower-robot)

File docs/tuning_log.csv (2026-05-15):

data | kp | ki | kd | base_speed | max_speed | min_speed | threshold | melhor_volta_s | observacoes
2026-05-14 | 3.0 | 0.0 | 12.0 | 160 | 230 | 60 | 0.60 |  | baseline — parametros iniciais config.h

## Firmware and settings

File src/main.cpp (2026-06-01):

// orquestração principal LFR — Line Follower Racer
// Core 0: controle (sensor→PID→motor, < 2ms)
// Core 1: comunicação (BLE + telemetria JSON @ 30 Hz)
#ifndef NATIVE_BUILD

#include <Arduino.h>
#include <SPI.h>
#include <atomic>

#include "config.h"
#include "sensors/Calibration.h"
#include "sensors/SensorArray.h"
#include "control/PIDController.h"
#include "control/SpeedProfile.h"
#include "motors/MotorDriver.h"
#include "motors/DifferentialDrive.h"
#include "strategy/LineFollower.h"
#include "strategy/LapTimer.h"
#include "comm/BLETuner.h"
#include "comm/Logger.h"
#include "sensors/Encoder.h"
#include "sensors/VelocityEstimator.h"
#include "storage/NvsStore.h"
#include "control/CascadeController.h"

// ═══ Estado da máquina ═════════════════════════════════════════════════════
enum class RobotState : uint8_t { IDLE, CALIBRATING, READY, RUNNING, ERROR };

// ═══ Módulos — Dependency Injection no construtor ══════════════════════════
static Calibration calibration(SENSOR_COUNT);

static SensorArray sensors(
    PIN_SPI_CS,
    SPI_FREQ,
    SENSOR_COUNT,
    calibration
);

static PIDController pid(
    KP_DEFAULT, KI_DEFAULT, KD_DEFAULT,
    -static_cast<float>(PWM_MAX),
    +static_cast<float>(PWM_MAX)
);

static SpeedProfile speedProfile(
    MIN_SPEED, BASE_SPEED_DEFAULT, MAX_SPEED, ERROR_THRESHOLD
);

static DifferentialDrive drive(PWM_MAX);
static LineFollower lineFollower(calibration, pid, speedProfile, drive);
static LapTimer lapTimer;

static BLETuner ble;
static Logger   logger;

static MotorDriver::Config cfgA = {
    PIN_MOTOR_A_PWM, PIN_MOTOR_A_IN1, PIN_MOTOR_A_IN2, 0, PWM_FREQ, PWM_RESOLUTION
};
static MotorDriver::Config cfgB = {
    PIN_MOTOR_B_PWM, PIN_MOTOR_B_IN1, PIN_MOTOR_B_IN2, 1, PWM_FREQ, PWM_RESOLUTION
};
static MotorDriver motors(cfgA, cfgB, PIN_MOTOR_STBY);

// ═══ Cascade PID — Fase C ════════════════════════════════════════════════════
static Encoder encL(PIN_ENC_LEFT_A,  PIN_ENC_LEFT_B);
static Encoder encR(PIN_ENC_RIGHT_A, PIN_ENC_RIGHT_B);

static NvsStore nvs;
static VelocityEstimator velL(encL, nvs, "left");
static VelocityEstimator velR(encR, nvs, "right");

static PIDController pidVelL(
    KP_VEL_DEFAULT, KI_VEL_DEFAULT, KD_VEL_DEFAULT,
    -static_cast<float>(PWM_MAX), +static_cast<float>(PWM_MAX), 0.002f);
static PIDController pidVelR(
    KP_VEL_DEFAULT, KI_VEL_DEFAULT, KD_VEL_DEFAULT,
    -static_cast<float>(PWM_MAX), +static_cast<float>(PWM_MAX), 0.002f);

static CascadeController cascade(pidVelL, pidVelR, MAX_RPM_DEFAULT, PWM_MAX);

// ═══ Estado compartilhado Core 0 → Core 1 ══════════════════════════════════
struct TelemetrySnapshot {
    float    pos       = 0.0f;
    float    corr      = 0.0f;
    int      vL        = 0;
    int      vR        = 0;
    uint32_t dtUs      = 0;
    float    rpmL      = 0.0f;
    float    rpmR      = 0.0f;
    float    setpointL = 0.0f;
    float    setpointR = 0.0f;
    float    sensorsPct[SENSOR_COUNT] = {};  // [0–100]
};

static TelemetrySnapshot   g_snap;
static portMUX_TYPE        g_snapMux        = portMUX_INITIALIZER_UNLOCKED;
static volatile float      g_baseRpm        = BASE_RPM_DEFAULT;  // mutável via BLE
static std::atomic<RobotState> robotState{RobotState::IDLE};
static portMUX_TYPE        lineFollowerMux  = portMUX_INITIALIZER_UNLOCKED;
static uint32_t            calStart         = 0;
static constexpr uint32_t  CAL_DURATION_MS  = 5000;

// Estado do cascade — escopo de arquivo p/ permitir reset em transições READY→RUNNING.
// M-1 (Reviewer) + MS-1 (Security): stale prevLoopStart causa dt fora de escala
// no 1º tick após re-entry; encoders acumulam pulsos durante IDLE/READY.
static uint32_t g_prevLoopStart = 0;

static void resetCascadeState() {
    g_prevLoopStart = 0;
    velL.update(0);   // Fase B: update(0) drena delta sem atualizar IIR
    velR.update(0);
}

// ═══ Bateria ════════════════════════════════════════════════════════════════
// Divisor: 100 kΩ / 47 kΩ → Vout = Vin × 47/147. LiPo 2S: 6.4–8.4 V.
static float readBatteryPct() {
    const int   raw  = analogRead(PIN_VBAT_ADC);
    const float vout = (raw / 4095.0f) * 3.3f;
    const float vin  = vout * (100.0f + 47.0f) / 47.0f;
    const float pct  = (vin - 6.4f) / (8.4f - 6.4f) * 100.0f;
    return std::max(0.0f, std::min(100.0f, pct));
}

// ═══ Helpers de hardware ════════════════════════════════════════════════════
static void beep(uint32_t ms) {
    digitalWrite(PIN_BUZZER, HIGH);
    uint32_t t = millis();
    while (millis() - t < ms) {}
    digitalWrite(PIN_BUZZER, LOW);
}

static inline bool btnPressed() {
    return digitalRead(PIN_BTN_START) == LOW;
}

// ═══ Task Core 1 — BLE + Telemetria JSON ════════════════════════════════════
static void taskComm(void* /*pvParameters*/) {
    ble.begin("LFR-RACER-01");

    int   telTick = 0;
    int   batTick = 0;
    float batPct  = 100.0f;
    float bestLap = 0.0f;
    bool  hasLap  = false;
    float laps[5] = {};
    int   nLaps   = 0;

    uint32_t lastLapMs = 0;  // detecta quando LapTimer registra uma nova volta

    for (;;) {
        ble.update();

        // Envia frame de identificação ao cliente recém-conectado
        if (ble.consumeNewConnection()) {
            ble.notifyInfo("LFR-RACER-01", "v3.1.0", "RUN");
        }

        // Aplica parâmetros PID recebidos via BLE
        if (ble.hasNewPID()) {
            PIDParams p = ble.getPID();
            taskENTER_CRITICAL(&lineFollowerMux);
            lineFollower.setPID(p.kp, p.ki, p.kd);
            taskEXIT_CRITICAL(&lineFollowerMux);
        }

        // Aplica parâmetros de velocidade recebidos via BLE
        if (ble.hasNewSpeed()) {
            SpeedParams s = ble.getSpeed();
            taskENTER_CRITICAL(&lineFollowerMux);
            lineFollower.setSpeed(s.minSpeed, s.baseSpeed, s.maxSpeed, s.threshold);
            taskEXIT_CRITICAL(&lineFollowerMux);
        }

        // Aplica ganhos do PID interno de velocidade
        if (ble.hasNewVelocityPID()) {
            VelocityPIDParams p = ble.getVelocityPID();
            // Hardening (Wave 3): ganho negativo inverte o sinal da malha
            // (realimentação positiva → descontrole). NaN/Inf → 0. Piso em 0.
            float kp = (std::isfinite(p.kp) && p.kp >= 0.0f) ? p.kp : 0.0f;
            float ki = (std::isfinite(p.ki) && p.ki >= 0.0f) ? p.ki : 0.0f;
            float kd = (std::isfinite(p.kd) && p.kd >= 0.0f) ? p.kd : 0.0f;
            taskENTER_CRITICAL(&lineFollowerMux);
            cascade.setInnerGains(kp, ki, kd);
            taskEXIT_CRITICAL(&lineFollowerMux);
        }

        // Aplica novo MAX_RPM (clamp do cascade)
        if (ble.hasNewRpm()) {
            RpmParams r = ble.getRpm();
            // Hardening (Wave 3): clampa comandos BLE à faixa física antes de
            // tocar a malha. max inválido/≤0 → default; base confinada a [0,max].
            float maxRpm  = (std::isfinite(r.maxRpm) && r.maxRpm > 0.0f)
                          ? (r.maxRpm < RPM_HARD_CEILING ? r.maxRpm : RPM_HARD_CEILING)
                          : MAX_RPM_DEFAULT;
            float baseRpm = (std::isfinite(r.baseRpm) && r.baseRpm >= 0.0f)
                          ? (r.baseRpm < maxRpm ? r.baseRpm : maxRpm)
                          : 0.0f;
            taskENTER_CRITICAL(&lineFollowerMux);
            cascade.setMaxRpm(maxRpm);
            g_baseRpm = baseRpm;
            taskEXIT_CRITICAL(&lineFollowerMux);
        }

        // Comando de calibração de encoder
        if (ble.hasNewCalibration()) {
            CalibrationCmd c = ble.getCalibration();
            VelocityEstimator& target = c.leftSide ? velL : velR;
            if (c.op == CalibrationCmd::Op::START) {
                target.startCalibration();
                beep(50);
            } else if (c.op == CalibrationCmd::Op::FINISH) {
                bool ok = target.finishCalibration(c.rotations);
                beep(ok ? 200 : 500);
                char buf[40];
                snprintf(buf, sizeof(buf), "%.2f", target.getEffectivePPR());
                // NOTE: notifyInfo(name, fw, mode) — fw/mode fields are repurposed
                // as status/value for this confirmation message. Tracked as known
                // deviation; proper fix (new overload) is out of Fase D scope.
                ble.notifyInfo(c.leftSide ? "CAL_L" : "CAL_R",
                               ok ? "OK" : "FAIL", buf);
            }
        }

        // Comandos de controle remoto via BLE
        if (ble.consumeStart() && robotState.load() == RobotState::READY) {
            pid.reset();
            lineFollower.reset();
            resetCascadeState();
            lapTimer.start(millis());
            logger.setEnabled(true);
            robotState.store(RobotState::RUNNING, std::memory_order_release);
            beep(50);
        }
        if (ble.consumeStop() && robotState.load() == RobotState::RUNNING) {
            motors.stop();
            logger.setEnabled(false);
            robotState.store(RobotState::READY, std::memory_order_release);
            beep(300);
        }
        if (ble.consumeReset()) {
            motors.stop();
            logger.setEnabled(false);
            lapTimer.reset();
            hasLap = false;
            nLaps  = 0;
            robotState.store(RobotState::IDLE, std::memory_order_release);
            beep(100);
        }

        // Bateria: leitura a cada ~1 s (100 × 10 ms)
        if (++batTick >= 100) {
            batTick = 0;
            batPct  = readBatteryPct();
        }

        // Telemetria JSON @ 30 Hz (cada 3 ticks de 10 ms)
        if (++telTick >= 3) {
            telTick = 0;

            TelemetrySnapshot snap;
            taskENTER_CRITICAL(&g_snapMux);
            snap = g_snap;
            taskEXIT_CRITICAL(&g_snapMux);

            // Sincroniza voltas com LapTimer
            uint32_t currLapMs = lapTimer.getLastLapMs();
            if (currLapMs > 0 && currLapMs != lastLapMs) {
                lastLapMs = currLapMs;
                // Insere no início do histórico (shift right, máx 5 entradas)
                int shift = (nLaps < 5) ? nLaps : 4;
                for (int i = shift; i > 0; i--) laps[i] = laps[i - 1];
                laps[0] = currLapMs / 1000.0f;
                if (nLaps < 5) nLaps++;
            }
            uint32_t bestMs = lapTimer.getBestLapMs();
            if (bestMs > 0) {
                hasLap  = true;
                bestLap = bestMs / 1000.0f;
            }

            ble.notifyTelemetry(
                snap.pos, snap.corr, snap.vL, snap.vR, snap.dtUs,
                snap.rpmL, snap.rpmR, snap.setpointL, snap.setpointR,
                snap.sensorsPct, SENSOR_COUNT,
                batPct, bestLap, hasLap, laps, nLaps
            );

            // Buffer CSV de debug (opcional — pode ser redirecionado p/ SPIFFS)
            logger.drain([](const char* /*csv*/) {});
        }

        vTaskDelay(pdMS_TO_TICKS(10));  // 100 Hz poll
    }
}

// ═══ Setup ══════════════════════════════════════════════════════════════════
void setup() {
    SPI.begin(PIN_SPI_CLK, PIN_SPI_MISO, PIN_SPI_MOSI, PIN_SPI_CS);
    sensors.begin();
    motors.begin();
    encL.begin();
    encR.begin();
    nvs.begin("lfr");
    velL.begin();
    velR.begin();
    analogReadResolution(12);

    pinMode(PIN_BTN_START,  INPUT_PULLUP);
    pinMode(PIN_BUZZER,     OUTPUT);
    pinMode(PIN_LED_STATUS, OUTPUT);
    digitalWrite(PIN_BUZZER,     LOW);
    digitalWrite(PIN_LED_STATUS, LOW);

    xTaskCreatePinnedToCore(taskComm, "Comm", 8192, nullptr, 1, nullptr, 1);

    robotState.store(RobotState::IDLE, std::memory_order_release);
    digitalWrite(PIN_LED_STATUS, HIGH);
    beep(100);
}

// ═══ Loop — Core 0 (controle tempo-real) ════════════════════════════════════
void loop() {
    switch (robotState.load(std::memory_order_acquire)) {

        case RobotState::IDLE:
            if (btnPressed()) {
                robotState.store(RobotState::CALIBRATING, std::memory_order_release);
                calStart = millis();
                calibration.reset();
                sensors.begin();
                beep(100);
                digitalWrite(PIN_LED_STATUS, LOW);
            }
            break;

        case RobotState::CALIBRATING: {
            int raw[SENSOR_COUNT];
            sensors.readAll(raw);
            calibration.update(raw);
            digitalWrite(PIN_LED_STATUS, (millis() / 200) % 2);
            if (millis() - calStart >= CAL_DURATION_MS) {
                robotState.store(RobotState::READY, std::memory_order_release);
                digitalWrite(PIN_LED_STATUS, LOW);
                beep(200);
            }
            break;
        }

        case RobotState::READY:
            digitalWrite(PIN_LED_STATUS, HIGH);
            if (btnPressed()) {
                pid.reset();
                lineFollower.reset();
                resetCascadeState();
                lapTimer.start(millis());
                logger.setEnabled(true);
                robotState.store(RobotState::RUNNING, std::memory_order_release);
                beep(50);
            }
            break;

        case RobotState::RUNNING: {
            uint32_t loopStart = micros();
            // MED-1: dt real; M-1: g_prevLoopStart é resetado em resetCascadeState()
            // a cada re-entry no estado, evitando dt stale após STOP/START.
            uint32_t dtMs = (g_prevLoopStart == 0) ? 2 : ((loopStart - g_prevLoopStart) / 1000);
            g_prevLoopStart = loopStart;

            // 1. Atualiza estimadores de velocidade com dt real do loop
            velL.update(dtMs);
            velR.update(dtMs);

            // 2. Lê sensores de linha
            int raw[SENSOR_COUNT];
            sensors.readAll(raw);

            // 3. PID externo via LineFollower (dentro do mux crítico).
            //    discardL/R são ignorados — pegamos a correção pura via getLastCorrection().
            int   discardL = 0;
            int   discardR = 0;
            float normErr  = 0.0f;

            taskENTER_CRITICAL(&lineFollowerMux);
            lineFollower.update(raw, discardL, discardR, &normErr);
            // HIGH-1: usa getLastCorrection() para evitar perda de informação
            // quando os PWMs ficam clamped (fórmula (L-R)/2 fica incorreta nesses casos).
            float correctionPwm = lineFollower.getLastCorrection();
            taskEXIT_CRITICAL(&lineFollowerMux);

            // 4. Converte correção PWM-scale → RPM-scale para o cascade.
            // H-1 (Reviewer): correctionPwm tem range [-PWM_MAX, +PWM_MAX]; deve
            // mapear para [-MAX_RPM, +MAX_RPM] para preservar autoridade total da
            // malha externa. Usar BASE_RPM aqui comprimia o range em ~50%.
            float correctionRpm = correctionPwm * (MAX_RPM_DEFAULT / static_cast<float>(PWM_MAX));

            // 5. Valida RPM (NVS pode ter retornado NaN/Inf na primeira leitura).
            float rpmLActual = velL.getRPM();
            float rpmRActual = velR.getRPM();
            if (!std::isfinite(rpmLActual)) rpmLActual = 0.0f;
            if (!std::isfinite(rpmRActual)) rpmRActual = 0.0f;

            // 6. Cascade: fecha malha de velocidade em ambos os motores.
            int leftPwm  = 0;
            int rightPwm = 0;
            cascade.compute(correctionRpm, g_baseRpm,
                            rpmLActual, rpmRActual,
                            leftPwm, rightPwm);

            // 7. Aplica PWM nos motores
            motors.setSpeed(MotorId::A, leftPwm);
            motors.setSpeed(MotorId::B, rightPwm);

            uint32_t dtUs = micros() - loopStart;

            // Atualiza snapshot de telemetria para o Core 1
            {
                int norm[SENSOR_COUNT];
                calibration.normalize(raw, norm);
                taskENTER_CRITICAL(&g_snapMux);
                g_snap.pos       = normErr * 3500.0f;
                // M-2 (Reviewer): semântica de `corr` agora é diff dos PWMs internos do
                // cascade (não mais saída do PID externo). Renomear o campo é Fase D scope;
                // por ora documentamos. Para correção pura da malha externa, usar telemetry
                // de getLastCorrection() (a expor) em Fase D.
                g_snap.corr      = static_cast<float>(leftPwm - rightPwm);
                g_snap.vL        = leftPwm;
                g_snap.vR        = rightPwm;
                g_snap.dtUs      = dtUs;
                // C-1 (Reviewer): reusa rpmLActual/rpmRActual já validados via isfinite
                // em vez de chamar getRPM() de novo (TOCTOU defensivo).
                g_snap.rpmL      = rpmLActual;
                g_snap.rpmR      = rpmRActual;
                g_snap.setpointL = g_baseRpm + correctionRpm;
                g_snap.setpointR = g_baseRpm - correctionRpm;
                for (int i = 0; i < SENSOR_COUNT; i++)
                    g_snap.sensorsPct[i] = norm[i] / 10.0f;  // [0–1000] → [0–100]
                taskEXIT_CRITICAL(&g_snapMux);
            }

#ifdef DEBUG_LOG
            if (logger.isEnabled()) {
                LogEntry entry;
                entry.ts         = millis();
                entry.position   = normErr * 3500.0f;
                entry.error      = normErr;
                entry.termP      = normErr * pid.getKp();
                entry.termI      = 0.0f;
                entry.termD      = 0.0f;
                entry.correction = static_cast<float>(leftPwm - rightPwm);
                entry.vLeft      = leftPwm;
                entry.vRight     = rightPwm;
                entry.dtUs       = dtUs;
                logger.push(entry);
            }
#else
            (void)dtUs;
#endif

            if (btnPressed()) {
                motors.stop();
                logger.setEnabled(false);
                robotState.store(RobotState::READY, std::memory_order_release);
                beep(300);
            }

            if (dtUs > 4000) {
                motors.stop();
                robotState.store(RobotState::ERROR, std::memory_order_release);
            }
            break;
        }

        case RobotState::ERROR:
            motors.stop();
            logger.setEnabled(false);
            digitalWrite(PIN_LED_STATUS, (millis() / 200) % 2);
            if (btnPressed()) {
                robotState.store(RobotState::IDLE, std::memory_order_release);
                beep(100);
            }
            break;
    }
}

#endif  // NATIVE_BUILD

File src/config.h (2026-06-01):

#pragma once

// ═══ PINAGEM ESP32 DevKit V1 ═══
#define PIN_SPI_MOSI        13
#define PIN_SPI_MISO        12
#define PIN_SPI_CLK         14
#define PIN_SPI_CS          15

#define PIN_MOTOR_A_PWM     25
#define PIN_MOTOR_A_IN1     26
#define PIN_MOTOR_A_IN2     27
#define PIN_MOTOR_B_PWM     33
#define PIN_MOTOR_B_IN1     32
#define PIN_MOTOR_B_IN2      4
#define PIN_MOTOR_STBY      23

// ═══ ENCODERS Hall (Fase A — leitura quadratura 4×) ════════════════════════
// GPIO 36 e 39 são input-only no ESP32 e não têm pull-up interno: use 10kΩ externo.
// Resolução: 4 transições por período × PPR efetivo (medido na Fase B).
#define PIN_ENC_LEFT_A      18
#define PIN_ENC_LEFT_B      19
#define PIN_ENC_RIGHT_A     36
#define PIN_ENC_RIGHT_B     39

#define PIN_BTN_START        0
#define PIN_BUZZER          22
#define PIN_LED_STATUS       2
#define PIN_VBAT_ADC        34

// ═══ PID DEFAULTS ═══
#define KP_DEFAULT          3.0f
#define KI_DEFAULT          0.0f
#define KD_DEFAULT          12.0f

// ═══ VELOCIDADE ═══
#define BASE_SPEED_DEFAULT  160
#define MAX_SPEED           230
#define MIN_SPEED            60
#define ERROR_THRESHOLD     0.6f

// ═══ SENSORES ═══
#define SENSOR_COUNT          8
#define SENSOR_SPACING_MM    10
#define SENSOR_HEIGHT_MM      4
#define LOOKAHEAD_MM         70

// ═══ ENCODER / VELOCITY (Fase B) ═══════════════════════════════════════════
// PPR_X4 default = 4 × PPR motor. N20 com encoder Hall típico = 7 PPR → 28 X4.
// Auto-calibração via BLE sobrescreve esse valor e salva em NVS.
#define ENCODER_DEFAULT_PPR_X4   28.0f
#define VELOCITY_FILTER_ALPHA    0.3f  // 0 ≤ α ≤ 1 — menor = mais suave, mais delay (α=0 congela)

// ═══ CASCADE PID (Fase C — controle interno de velocidade) ═════════════════
// Ganhos INICIAIS conservadores; sintonizar via BLE em pista.
#define KP_VEL_DEFAULT   0.8f
#define KI_VEL_DEFAULT   0.0f
#define KD_VEL_DEFAULT   0.05f

// Faixa esperada de RPM no shaft de saída — N20 1500 RPM @ 6V.
// MAX_RPM é o teto absoluto (clamp); BASE_RPM é o alvo nominal em reta.
#define MAX_RPM_DEFAULT  1200.0f
#define BASE_RPM_DEFAULT  600.0f

// Teto físico absoluto p/ comandos de RPM vindos via BLE. Impede que um write
// malicioso/acidental comande velocidade fora da faixa física do N20
// (~1500 RPM @ 6V) — evita runaway e overflow do buffer de telemetria.
#define RPM_HARD_CEILING 2000.0f

// ═══ PWM LEDC ═══
#define PWM_FREQ         20000
#define PWM_RESOLUTION      10
#define PWM_MAX           1023

// ═══ SPI ═══
#define SPI_FREQ        1000000

// ═══ TIMING ═══
#define LOOP_PERIOD_US    2000

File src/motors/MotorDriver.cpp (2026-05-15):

#include "motors/MotorDriver.h"
#include <algorithm>

#ifndef NATIVE_BUILD
#include <Arduino.h>

MotorDriver::MotorDriver(const Config& configA, const Config& configB, uint8_t stbyPin)
    : _cfgA(configA), _cfgB(configB), _stbyPin(stbyPin), _initialized(false) {}

void MotorDriver::begin() {
    pinMode(_stbyPin, OUTPUT);
    digitalWrite(_stbyPin, HIGH);  // sai do standby

    auto initChannel = [](const Config& cfg) {
        ledcSetup(cfg.ledcChannel, cfg.pwmFreq, cfg.pwmResolution);
        ledcAttachPin(cfg.pwmPin, cfg.ledcChannel);
        pinMode(cfg.in1Pin, OUTPUT);
        pinMode(cfg.in2Pin, OUTPUT);
    };
    initChannel(_cfgA);
    initChannel(_cfgB);
    _initialized = true;
    stop();
}

void MotorDriver::_writePwm(const Config& cfg, uint32_t duty) {
    ledcWrite(cfg.ledcChannel, duty);
}

void MotorDriver::_applyMotor(const Config& cfg, int pwm) {
    if (pwm > 0) {
        digitalWrite(cfg.in1Pin, HIGH);
        digitalWrite(cfg.in2Pin, LOW);
        _writePwm(cfg, static_cast<uint32_t>(pwm));
    } else if (pwm < 0) {
        digitalWrite(cfg.in1Pin, LOW);
        digitalWrite(cfg.in2Pin, HIGH);
        _writePwm(cfg, static_cast<uint32_t>(-pwm));
    } else {
        // pwm == 0: brake
        digitalWrite(cfg.in1Pin, HIGH);
        digitalWrite(cfg.in2Pin, HIGH);
        _writePwm(cfg, 0);
    }
}

void MotorDriver::setSpeed(MotorId motor, int pwm) {
    const Config& cfg = (motor == MotorId::A) ? _cfgA : _cfgB;
    const int maxDuty = (1 << cfg.pwmResolution) - 1;
    pwm = std::max(-maxDuty, std::min(maxDuty, pwm));
    _applyMotor(cfg, pwm);
}

void MotorDriver::brake(MotorId motor) {
    const Config& cfg = (motor == MotorId::A) ? _cfgA : _cfgB;
    digitalWrite(cfg.in1Pin, HIGH);
    digitalWrite(cfg.in2Pin, HIGH);
    _writePwm(cfg, 0);
}

void MotorDriver::coast(MotorId motor) {
    const Config& cfg = (motor == MotorId::A) ? _cfgA : _cfgB;
    digitalWrite(cfg.in1Pin, LOW);
    digitalWrite(cfg.in2Pin, LOW);
    _writePwm(cfg, 0);
}

void MotorDriver::standby(bool enable) {
    digitalWrite(_stbyPin, enable ? LOW : HIGH);
}

void MotorDriver::stop() {
    brake(MotorId::A);
    brake(MotorId::B);
}

#else
// Stubs para compilação native (testes)
MotorDriver::MotorDriver(const Config& a, const Config& b, uint8_t s)
    : _cfgA(a), _cfgB(b), _stbyPin(s), _initialized(false) {}
void MotorDriver::begin() {}
void MotorDriver::setSpeed(MotorId, int) {}
void MotorDriver::brake(MotorId) {}
void MotorDriver::coast(MotorId) {}
void MotorDriver::standby(bool) {}
void MotorDriver::stop() {}
void MotorDriver::_applyMotor(const Config&, int) {}
void MotorDriver::_writePwm(const Config&, uint32_t) {}
#endif

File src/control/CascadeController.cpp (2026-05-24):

// src/control/CascadeController.cpp
#include "control/CascadeController.h"
#include <algorithm>
#include <cmath>

CascadeController::CascadeController(PIDController& innerLeft, PIDController& innerRight,
                                     float maxRpm, int maxPwm)
    : _pidL(innerLeft), _pidR(innerRight), _maxRpm(maxRpm), _maxPwm(maxPwm) {}

void CascadeController::compute(float correction, float targetBaseRpm,
                                float actualRpmL, float actualRpmR,
                                int& pwmL, int& pwmR) {
    // 0. Defense-in-depth: NaN/Inf em qualquer entrada vira 0.0f.
    // std::max/std::min com NaN retornam NaN silenciosamente → static_cast<int>(NaN)
    // é UB. Sanitização explícita evita o cast UB mesmo se a chain externa falhar.
    if (!std::isfinite(correction))    correction    = 0.0f;
    if (!std::isfinite(targetBaseRpm)) targetBaseRpm = 0.0f;
    if (!std::isfinite(actualRpmL))    actualRpmL    = 0.0f;
    if (!std::isfinite(actualRpmR))    actualRpmR    = 0.0f;

    // 1. Traduz correction + base em setpoints por motor.
    float setpointL = targetBaseRpm + correction;
    float setpointR = targetBaseRpm - correction;

    // 2. Clamp dos setpoints (proteção contra over-PID externo).
    setpointL = _clampF(setpointL, -_maxRpm, +_maxRpm);
    setpointR = _clampF(setpointR, -_maxRpm, +_maxRpm);

    // 3. PID interno: erro = setpoint − measurement → saída em PWM.
    float outL = _pidL.compute(setpointL, actualRpmL);
    float outR = _pidR.compute(setpointR, actualRpmR);

    // 4. Saturação final em PWM (já vem clamped pelo PIDController, mas garantimos
    //    cast seguro para int e respeito ao limite externo se setMaxPwm() mudou).
    outL = _clampF(outL, -static_cast<float>(_maxPwm), +static_cast<float>(_maxPwm));
    outR = _clampF(outR, -static_cast<float>(_maxPwm), +static_cast<float>(_maxPwm));
    // Guarda final contra NaN remanescente (PID interno pode produzir se ki=0 e
    // _prevMeasurement vier corrompido) — std::isfinite garante cast seguro.
    if (!std::isfinite(outL)) outL = 0.0f;
    if (!std::isfinite(outR)) outR = 0.0f;
    pwmL = static_cast<int>(outL);
    pwmR = static_cast<int>(outR);
}

void CascadeController::setInnerGains(float kp, float ki, float kd) {
    _pidL.setTunings(kp, ki, kd);
    _pidR.setTunings(kp, ki, kd);
    // MS-2: reset() limpa _prevMeasurement e _integral.
    // Sem isso, BLE retune com motores rodando emite um pico de derivada
    // (Kd × erro stale) que pode descontrolar a malha por algumas iterações.
    _pidL.reset();
    _pidR.reset();
}

void CascadeController::setMaxRpm(float maxRpm) { _maxRpm = maxRpm; }
void CascadeController::setMaxPwm(int   maxPwm) { _maxPwm = maxPwm; }

float CascadeController::_clampF(float v, float lo, float hi) const {
    return std::max(lo, std::min(hi, v));
}

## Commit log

2026-05-15 feat: Fase 0-3 completa — 39 testes passando, firmware compilável
    - platformio.ini: native + esp32dev, Unity, NimBLE, test_ignore=test_sensors
    - src/config.h: todas constantes do projeto (PID, velocidade, sensores, pinout)
    - src/control/: PIDController (derivada no processo, anti-windup) + SpeedProfile
    - src/sensors/: Calibration (min/max, posição ponderada) + SensorArray (MCP3008 SPI)
    - src/motors/: MotorDriver (TB6612FNG + LEDC PWM) + DifferentialDrive
    - src/strategy/LineFollower: orquestração sensor→PID→motor
    - src/comm/: BLETuner (Kp/Ki/Kd/speed via NimBLE) + Logger (buffer circular CSV)
    - src/main.cpp: máquina de estados IDLE→CALIBRATING→READY→RUNNING→ERROR, dual-cor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
    [BLETuner.h, LineFollower.cpp]
2026-05-15 fix: aplicar revisão C++ — thread-safety, heap, integridade do PID e dead state
    [CRITICAL] main.cpp: std::atomic<RobotState> com memory_order_release/acquire
    substitui volatile que não garante barriers SMP no Xtensa dual-core
    [CRITICAL] main.cpp: portMUX_TYPE spinlock para lineFollower::update/setPID/setSpeed
    elimina data race entre Core 0 (loop) e Core 1 (taskComm)
    [CRITICAL] BLETuner: portMUX spinlock em toda state compartilhada (pid/speed/flags)
    + comparação por ponteiro de char em vez de UUID string (elimina heap no callback)
    [HIGH] Calibration: substituir new int[] por int[MAX_SENSORS] estático
    + delete copy/move (Rule of Zero) + assert de precondição no construtor
    [HIG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
    [BLETuner.h, MotorDriver.cpp]
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2026-05-15 feat: Fase 6 — LapTimer + VelocityProfile TDD + relatório final
    TDD estrito (Red→Green→Refactor), 47/47 testes passando:
    LapTimer (src/strategy/):
    - start(ts)/notifyLineCrossing(ts)/reset() — timestamps injetados (testável)
    - Rastreia última volta, melhor volta, contador de voltas
    - 4 testes: estado inicial, registro, melhor volta, reset
    VelocityProfile (src/control/):
    - Buffer circular 8 posições para predição de curvatura
    - getCurvatureScore(): velocidade média de mudança de posição [0,1]
    - computeSpeed(): min(errorSpeed, effectiveMax) com penalidade de curvatura
    - 4 testes: zero erro, máximo erro, predição de curva, buffer wrap
    docs/RELATORIO_FINAL.md: arquitetura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
2026-05-20 test(encoder): add 9 failing tests for quadrature 4x decoder
    [test_encoder.cpp]
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2026-05-20 fix(encoder): remove IRAM_ATTR from class-member declaration
    ESP32 GCC parses 'static void IRAM_ATTR _isrTrampoline(...)' in a class
    body as a stray identifier — "variable or field 'IRAM_ATTR' declared
    void". The attribute belongs only on the out-of-class definition in
    Encoder.cpp, where it correctly places the function in IRAM.
    Native tests (9/9) still pass; ESP32 compilation of Encoder.cpp now
    proceeds past the header (remaining failure is unrelated pre-existing
    DifferentialDrive bug in main.cpp).
2026-05-20 chore: restore ESP32 build (fixes from Fase 7 regressions)
    Two pre-existing bugs in main were blocking the ESP32 build since Fase 7
    (commit 456d00d). Project had only been validated via native tests.
    1. main.cpp:45 — DifferentialDrive was being constructed with 3 args
    (BASE_SPEED_DEFAULT, MIN_SPEED, PWM_MAX) but the API takes only
    maxPwm. The other two values are passed per-call via compute().
    2. BLETuner.cpp — the BLETuner() default constructor was defined only
    in the #else NATIVE_BUILD branch, so the ESP32 link failed with
    "undefined reference to BLETuner::BLETuner()". Moved the trivial
    definition outside the #ifdef so it applies to both targets.
    Surfaced while valida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
    [main.cpp]
2026-05-21 fix(encoder): apply Wave 3 review findings (HIGH + MEDIUM + LOW)
    Address findings from Reviewer + Security Auditor in Wave 3 of the
    Fase A swarm. Eight items in a single commit since they're tightly
    coupled (the type change to uint32_t affects every call site).
    HIGH-1: signed integer overflow UB
    _count and _lastReadCount are now volatile uint32_t. Unsigned wrap
    is well-defined in C++. getDelta() computes (int32_t)(curr - last)
    which yields correct signed delta while |delta| < 2^31.
    HIGH-2: dual-core race in getDelta/getCount/reset
    Added portMUX_TYPE _mux + portENTER_CRITICAL/portEXIT_CRITICAL
    around the read-modify-write sequence in getDelta(), the snapshot
    in getCount(), and t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
    [Encoder.cpp]
2026-05-21 docs: document Fase A — Encoder module and pull-up requirement
    WIRING.md: explicit hardware checklist for GPIO 36/39 external pull-ups
    (addresses Wave 3 security finding — INPUT_PULLUP no-op on input-only
    RTC pins; floating pins cause spurious ISRs that destroy PID stability).
    CLAUDE.md: register Encoder.h/.cpp in src/sensors/ tree to keep the
    architecture diagram in sync with the codebase.
2026-05-21 test(velocity): add 10 failing tests for RPM + auto-calibration
    [test_velocity_estimator.cpp]
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2026-05-21 fix(velocity): apply Wave 3 review findings (HIGH + MED + LOW)
    Fase B swarm. All HIGH and MED items applied in a single commit since
    they share state (e.g., _calibrating flag, key buffer size).
    HIGH-1: NVS PPR loaded without sanity validation
    begin() now validates _pprX4 with std::isfinite() and range
    [PPR_MIN_SANE, PPR_MAX_SANE]. NaN/Inf/0/negative/absurd values fall
    back to ENCODER_DEFAULT_PPR_X4 instead of poisoning the IIR filter
    (NaN × anything = NaN forever).
    HIGH-2: NVS key 15-char limit silently truncated
    ESP-IDF NVS rejects keys > 15 chars; "_ppr" suffix consumes 4 chars
    so the prefix must be ≤ 11. C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
    [VelocityEstimator.cpp, config.h]
2026-05-21 test(cascade): add 8 failing tests for cascade PID controller
    [test_cascade.cpp]
2026-05-21 feat(strategy): expose last correction from LineFollower for cascade integration
    [LineFollower.cpp]
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2026-05-21 feat(main): cascade PID in RUNNING — exact correction + measured dt
    Apply all Architect corrections:
    - HIGH-1: use LineFollower::getLastCorrection() instead of broken (L-R)/2 formula
    - MED-1: measure actual loop dt via micros() instead of hardcoded 2ms constant
    - MED-2: retain lineFollowerMux critical section around update + getLastCorrection
    - isfinite guard on RPM reads before passing to cascade
    [main.cpp]
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2026-05-24 fix(cascade): apply Wave 3 review findings (CRIT + HIGH + MED + LOW)
    Consolidate fixes from Reviewer + Security Auditor in Wave 3 of the
    Fase C swarm. All CRIT/HIGH and MED items applied; LOWs in the same
    files batched for efficiency.
    CRIT-1 (Reviewer): g_snap.rpmL/rpmR re-read getRPM() without isfinite
    Snapshot block now reuses rpmLActual/rpmRActual that were already
    validated. Defense-in-depth against future refactors that might move
    the snapshot away from the validated reads.
    HIGH-1 (Reviewer): correctionRpm formula used BASE_RPM_DEFAULT
    Outer PID output ranges [-PWM_MAX, +PWM_MAX]; correct scale factor
    is MAX_RPM_DEFAULT/PWM_MAX (not BASE_RPM_DEFAULT/PWM_MAX). Previous
    form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
    [CascadeController.cpp, Encoder.cpp, main.cpp]
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2026-08-12 fix(bom): replace TCRT5000 array with Pololu QTR-8A (D1)
    WIRING.md already specified the QTR-8A; bom.csv, CLAUDE.md and README.md
    still listed a generic 8x TCRT5000 module. They are different parts with
    different pitch (9.525 vs 10 mm) and different footprints.
    Figures from Pololu #960: 74.93x12.70x3.18 mm, 9.525 mm pitch, 3.09 g,
    3.3-5.0 V, 100 mA, USD 12.95.
    No BRL price: no Brazilian reseller found, and the landed cost depends on
    shipping and import tax. Left blank rather than invented; BOM total drops
    to R$383 and now states the exclusion explicitly.
    Also aligns the TOTAL row to the price_brl column (it was one column off).
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2026-10-13 docs(plans): LFR v2 master orchestration plan and WP1/WP2/WP3 implementation plans
    Spec amended with planning findings: lost line runs at vmin, 85 mm lookahead
    (70 mm collides with battery cradle and motor clamps), cradle integrated in the
    base, shims under the bar tongue to keep the chassis level.
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2026-10-13 feat(cad): assembly checks for interference, clearance, envelope, CG and skid load
    Result with plan layout (lookahead 85 mm unchanged): 227 g, CG (14.2, 0.1,
    20.3) mm, 16.7 % of the weight on the skids, wheel clearance 0.60 mm,
    envelope 177.8 x 104.0 x 55.6 mm.
    Deviation: Params.roda_aro_w 8.5 -> 8.2 mm. With 8.5 the wheel rim's inner
    face sat 0.3 mm from the base tab under the motor (eixo_l - aro_w -
    parede_batente = 10 - 8.5 - 1.2), failing test_roda_tem_folga_minima
    (>= 0.5). None of the Task 7 layout parameters can change that gap: it is
    fixed relative to the gearbox face. 8.2 leaves 0.6 mm and keeps the rim
    lip above the groove at 1.25 mm (>= 1.2 wall). Ficha/prancha 08 follow.
    Co-Aut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
2026-10-13 feat(cad): printability checks for bed size, walls and overhangs
    Measured overhang areas (mm2, limit): base 65.3 (100), clamp 11.1 (20),
    sensor bar 0.0 (10), skid 2.3 (5), shims 0 (0), wheel 5.2 (15).
    Deviation: skid.paredes() in the plan returned the 0.5 mm shim thickness,
    so the skid itself (not an exception) failed the 1.2 mm wall check. Split
    into skid.paredes() (skid walls, incl. 2 mm under the M2 pilot hole) and
    skid.paredes_calco() used by both shims, which stay in EXCECOES_PAREDE.
2026-10-13 feat(cad): printer tolerance coupon
    70 x 34 x 3 mm, 6054 mm3, 19 features; the 10 mm test key is also
    registered in printability ("cupom chave"). is_valid is a property in
    build123d 0.13 (the plan called it as a method).
2026-10-13 feat(cad): STL/STEP export and assembly report
    out/ generated by build.py: 10 parts (STL in print orientation, STEP in
    assembly position), assembly.step and relatorio_montagem.md. The STLs are
    added with -f because the root .gitignore ignores *.stl (spec 5.1 wants
    out/ committed; .gitignore left untouched).
    Deviation: the 10 x 10 mm test key gained a 3 mm push-out hole. As a plain
    box its binary STL was 684 bytes, below the 1000-byte floor of
    test_um_stl_e_um_step_por_peca; the hole is also useful to free the key
    from a tight blind pocket.
2026-10-13 chore(cad): retire OpenSCAD models and record divergences D11-D13
    D2, D3, D9, D10 resolved by the build123d model (lookahead 85 mm, track
    95.8 mm, 9.4 mm hub); D4 resolved by removing the caster; D7 stays open
    with the build.py report as the CG source; D11 (N20 gearbox height), D12
    (LOOKAHEAD_MM 70 -> 85 at merge) and D13 (A1/A2 superseded) added.
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2026-10-13 fix(line-follower): keep calibration on reset, saturate lost line, drop DifferentialDrive (F-01, F-14)
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2026-10-13 fix(encoder): internal pull-up on left encoder pins (F-24)
    GPIO 18/19 (left encoder) now use INPUT_PULLUP, as docs/WIRING.md already
    states. Input-only GPIO 34-39 (right encoder on 36/39) have no internal
    pull-up and stay INPUT with the external 10 kOhm resistor.
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2026-10-13 refactor(main): wiring-only main with control task on core 1 (F-09)
    main.cpp only wires modules: task control on core 1 (500 Hz,
    vTaskDelayUntil, priority configMAX_PRIORITIES-2), task comm on core 0
    (100 Hz), config/telemetry through Mailbox, state commands through a
    FreeRTOS queue. config.h drops the tuning defaults (now in RobotConfig),
    SENSOR_HEIGHT_MM = 3, adds VBAT_DIVIDER_RATIO and the buzzer LEDC channel.
    Addendum E-2: info carries uxTaskGetStackHighWaterMark of both tasks; the
    control task is created before comm so its handle exists when comm reads it.
    API adaptations found compiling for esp32dev (espressif32 6.13.0,
    arduino-esp32 2.0.17 / framework 3.20017.241212, NimBLE-Arduino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
2026-10-13 docs(avaliacao): independent geometric evaluation of WP2 CAD
    Verdict: approved with reservations. Independent OCP/trimesh checks
    reproduce zero interference over 105 pairs, 0.6 mm wheel clearance,
    sensor face at 3.000 mm and 16.7 % skid load. Two HIGH findings in
    build.py (no pass/fail checks for the assembler, no per-pair clearance
    report) and three MED (non-manifold patim.stl, M3 heads under the base,
    no QTR connector clearance).
2026-10-13 build(bench): one PlatformIO env per bench example, examples on new APIs
    - bench_motor, bench_encoder, bench_sensor_raw, bench_sensor_cal,
    bench_velocity_cal, bench_differential: each replaces main.cpp with its
    example; all six compile with 0 warnings from src/ and examples/.
    - velocity_calibration_test: VelocityEstimator::update takes microseconds.
    - differential_hw_test: rewritten on mixSteering + OutputStage
    (DifferentialDrive is gone).
    - sensor_calibration_test: drop unused buffer (-Wunused-variable) and use
    the white-line polarity, matching factory pol = 1 (F-03).
    Addendum F-30, versions pinned for esp32dev and every bench_* (inherited):
    platform espressif32@6.13.0 (framework-a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
2026-10-13 feat(dashboard): Web Bluetooth transport, config panel and v4 protocol simulator
    - lfr-cockpit-mock.html: BLE (Web Bluetooth, service 0xABCC) or WebSocket
    transport with the same JSON; CONFIG tab generated from CFG_KEYS (all
    spec 4.3 keys with range and unit), profile selector with in-page
    discard confirmation, SALVAR/RECARREGAR/FABRICA/CALIBRAR SENSORES, NAO
    SALVO indicator; tel/sta/cfg/ack/calres/ecal/info handled (state, error
    code, V_bat, ovr, cfgerr warning, stack headroom). PID/speed sliders send
    set on release in the new scales; BASE slider removed (F-15).
    Hardware keys and save/load/defaults/prof are disabled in ARMED/RUNNING.
    - lfr_sim.py: ConfigModel with the CommandH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
2026-10-13 feat(config): competition lock refuses BLE commands while armed or running (F-33)
    Emenda E-1 (spec 11): HardwareConfig::lock (u8, factory 0), key "lock"
    in group hw, range {0,1}, hardware = true, so it is itself refused in
    ARMED/RUNNING. With lock = 1, CommandHandler::handle refuses every BLE
    command while running with {"t":"ack","k":...,"ok":0,"err":"locked"}:
    one ack per key for set and the legacy pid/pidv/spd/rpm, the command name
    for get/save/load/defaults/prof/scal/start/stop/reset/cal; CmdType::NONE
    stays silent. No ControlMsg is produced, so nothing reaches the control
    task; telemetry keeps flowing and the button still stops the car. The hw
    blob changes size: an old blob loads as fact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
2026-10-14 fix(cad): build.py runs the acceptance checks and exits non-zero on failure (A-WP2-01)
    assembly.verificacoes() checks interference, wheel clearance >= 0.5 mm,
    skid load 10-20 %, CG ahead of the axle, ground clearance >= 4 mm, sensor
    face at 3.0 +/- 0.1 mm, skids and O-rings on the ground and the envelope.
    build.py writes a check/cross per item to relatorio_montagem.md; on any
    failure it still exports (for inspection), adds a NAO IMPRIMIR banner and
    exits 1. An invalid medidas.toml prints the error, exports nothing and
    exits 2. New --medidas/--saida options; tests cover the evaluator's
    83 x 42 mm holder (base x wheel 12.57 mm3, clearance 0.00 mm -> exit 1).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
2026-10-14 feat(cad): report minimum clearance per pair (A-WP2-02)
    assembly.folgas_por_par() measures the distance between every pair of
    printed parts, wheels and component envelopes (bounding-box pre-filter,
    wheel/own O-ring excluded) and returns the pairs closer than 2 mm.
    relatorio_montagem.md gets a 'Folgas por par' table. Values match the
    evaluator's independent measurement: clamp-motor 0.100, base-clamp 0.300,
    wheel-base 0.600, wheel-motor 0.600, clamp-wheel 0.906, clamp-holder
    1.500; support contacts at 0.000.
2026-10-14 fix(cad): skid cap tessellates as a closed single-body mesh (A-WP2-03)
    The skid cap was a sphere with its pole at the contact point; the STL got
    a loose degenerate triangle there. The sphere is now rotated so its poles
    lie on the Y axis, outside the |y| <= 3 mm trim box. Same solid (348.9
    mm3). test_build checks every exported STL with a dependency-free reader:
    no degenerate triangles, every edge shared by exactly 2 triangles, one
    connected body; a second test proves the checker flags a loose triangle.
2026-10-14 fix(cad): nothing fastened under the base enters the ground clearance (A-WP2-04)
    - The 2 M3 that hold the sensor-bar tongue are now ISO 10642 flat heads in
    a 90 deg countersink (D 7.0) on the underside of the base; 1.2 mm of plate
    is left above the cone. The head envelope sits flush (z 5.14).
    - The fuse-holder cable tie ran under the plate (z 3.8-3.9 with a 1.1-1.2
    mm tie): the two slots are now joined by a 1.6 mm recess on the underside
    and the tie envelope (z 5.4-6.6) stays inside the plate.
    - New parts/fixadores.py: envelopes of everything under the base (added to
    assembly.componentes, so they enter interference, clearance and the
    ground-clearance check, which now covers compo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
2026-10-14 fix(cad): sensor-bar posts on the QTR-8A's real mounting holes
    Found while working on A-WP2-05 (not in the evaluation): the Pololu
    dimension diagram (picture 0J623, docs/0J12/3) shows the two #2 mounting
    holes 2.75" apart next to the header edge, not on the board's centre line
    where the posts were. specs.py gains the official 69.85 mm hole spacing and
    the scaled-from-the-drawing (MEDIR) hole offset and header-field cotas;
    params reads qtr_furos_dist/qtr_furo_borda from it (both in medidas.toml).
    The QTR mounts component side up with the header edge to the rear, so the
    posts move to x = lookahead - 6.35 + 2.4 = 81.05 mm. D14 recorded.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
2026-10-14 feat(cad): QTR-8A connector window and wire route to the perfboard (A-WP2-05)
    - Header field of the QTR (2 rows, 2.54 mm, position scaled from the Pololu
    dimension diagram; qtr_pinos_borda/_ini/_fim are MEDIR keys in
    medidas.toml) gets a through window in the bar beam (6.1 x 29.2 mm, 0.5 mm
    around the connector; 2.33 mm of beam left behind it).
    - Connector envelope (header + Dupont-style housing, 16.5 mm above the
    board) and the wire-bundle envelope enter the interference, clearance and
    per-pair checks, with 0, 1 and 2 shims.
    - Route (parts/chicote.py): over the tongue, down a 4 x 7 mm notch at the
    rear end of the tongue and of the tongue shim, along a 7 x 1.8 mm open
    channel o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
2026-10-14 docs(divergencias): D8 follows the v2 model (A-WP2-14)
    The adjustment slot it cited no longer exists: the sensor face sits at
    3.0 mm by the model, and 0.5 mm shims under each skid and under the bar
    tongue raise it up to 6.0 mm. SENSOR_HEIGHT_MM in config.h is updated by
    the coordinator at merge, together with D12.
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2026-10-14 chore(cad): regenerate out/ after evaluation round 1
    build.py with the default medidas.toml: exit 0, all 8 checks pass.
    Lookahead 85 mm and O-ring 34 x 3 (wheel 40.9 mm) unchanged; skid load
    16.7 % -> 16.2 % and total mass 227 -> 225 g (connector window and wire
    notch remove PETG from the bar, posts moved to the real QTR holes). Every
    STL is a closed single-body mesh (patim.stl fixed).
2026-10-14 docs(spec,plan): stop-on-press (E-3) and encoder fault ERROR(ENC) (E-4), WP1 tasks 23-24
    Decided after the WP1 evaluation (A-WP1-02, A-WP1-03).
2026-10-14 fix(comm): send info on notification subscribe and in reply to get (A-WP1-01)
    The info frame (fw, cfgerr, stk) only went out right after onConnect,
    before any client can enable notifications, and get answered only cfg,
    so the dashboard never saw cfgerr or the stack headroom (E-2).
    - BLETuner: TelCallback::onSubscribe (NimBLE-Arduino 2.5.1 signature,
    subValue bit 0 = notify) raises a flag; consumeNewSubscription() reads
    it once. injectSubscribeForTest() drives the same path in native.
    - CommandHandler: sendInfo / sendInfoAndConfig; get now answers info
    followed by the cfg sequence. Info values come from a DeviceInfoFn
    (name, cfgerr, uxTaskGetStackHighWaterMark of both tasks), set by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
2026-10-14 fix(comm): drift-free 30 Hz telemetry pacing (A-WP1-06)
    The comm task runs every 10 ms and sent tel when now - lastTel >= 33 with
    lastTel = now, i.e. every 40 ms (25 Hz). PeriodicTimer advances its phase
    by the period instead, so polling every 10 ms averages 33.3 ms (30 Hz);
    after a stall longer than a period it fires once and resyncs (no burst),
    and it compares by signed difference across the millis() wraparound.
    New suite test_periodic_timer: 90 +- 1 events in 3 s polled every 10 ms,
    first call fires, no burst after a stall, wraparound.
2026-10-14 docs(avaliacao): WP2 round 1 re-evaluation
    A-WP2-01..05 and -14 closed and independently re-checked at a616ecf:
    build.py exits 0/1/2 with pass/fail checks, per-pair clearance table
    matches the evaluator's 32 pairs, all 10 STL closed single-body meshes,
    nothing but wheels/skids/QTR face below 5.0 mm, QTR connector window and
    wire route verified. Base overhang limit 125 mm2 accepted (3.5 mm
    bridge). New LOW: A-WP2-20 (O-ring range error exits 1 with traceback),
    A-WP2-21 (estimated QTR-8A offsets). Verdict: approved with reservations,
    no CRIT/HIGH/MED open.
2026-10-14 fix(encoder): one PPR range and publish the ecal result (A-WP1-04 b, c)
    (b) After cal finish the comm task wrote g_liveCfg.hw.ppr* directly and
    never posted it; a set arriving in between sent the old PPR back to the
    control task. CommandHandler::applyEncoderCalibration now mirrors the
    result through robotcfg::set (same range check), without dirty, and
    raises the changed flag; main posts the config to the Mailbox.
    (c) finishCalibration accepted any PPR > 0 and begin()/setPprX4 0.5-100000,
    while RobotConfig/ConfigStore accept 1-10000, so a PPR above 10000 made
    every save fail and was dropped at boot. ENCODER_PPR_X4_MIN/MAX in config.h
    is now the single range used by RobotConfig, ConfigStore a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
2026-10-14 fix(storage): atomic NVS arbiter between save/load/prof and arming (A-WP1-05)
    The comm task read g_state and then ran saveActive (5 NVS operations);
    meanwhile the control task could arm from the button and, with startMs 0,
    reach RUNNING, so the write landed in ARMED/RUNNING against spec 4.4.
    NvsArbiter (pure, header-only) holds one std::atomic<uint32_t> owner:
    FREE, NVS (comm) or ACTIVE (control), changed only by compare-and-swap, so
    whoever claims first wins with no check-then-act window. Each owner can
    only release its own state.
    - RobotStateMachine takes it optionally: entering ARMED claims ACTIVE (if
    the NVS is busy the transition is refused and the car stays READY);
    leaving ARMED/R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
2026-10-14 feat(safety): refuse start during encoder calibration, ERROR(ENC) on stalled feedback (E-4)
    Plan Task 24 (A-WP1-03). In cascade mode, with no valid RPM (calibration
    left open, encoder unplugged) the inner PIDs integrated to full duty
    whatever vmax was.
    - RobotStateMachine: SmInputs::encoderCalOpen; with it set, BTN_SHORT /
    CMD_START in READY do not arm (stay READY, no error).
    ErrorCode::ENC = 5 and SmEvent::ENCODER_FAULT (RUNNING -> ERROR(ENC)).
    - CommandHandler tracks cal start per side (finish closes that side, reset
    closes both); start with one open answers {"t":"ack","k":"start",
    "ok":0,"err":"cal"} and produces no ControlRequest::START.
    - ControlLoop: ControlOutputs::encoderFau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
